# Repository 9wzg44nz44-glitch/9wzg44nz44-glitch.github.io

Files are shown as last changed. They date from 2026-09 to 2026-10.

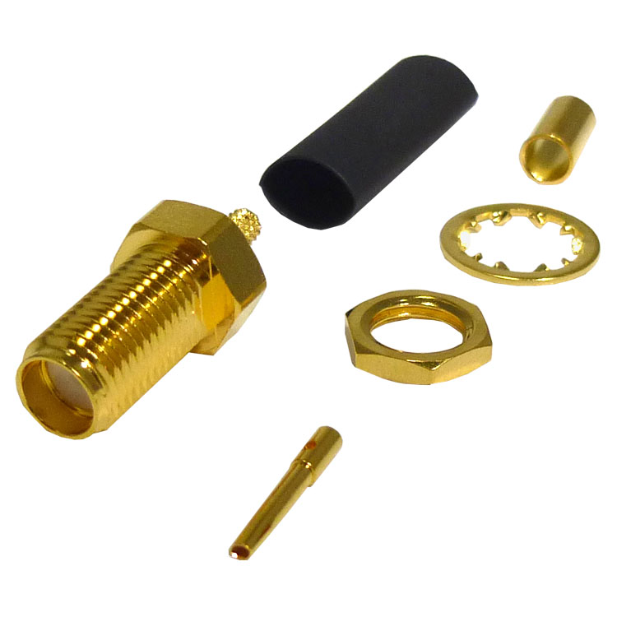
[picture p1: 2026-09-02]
img/901-9875.jpg

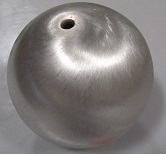
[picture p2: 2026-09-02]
img/kmac-alum-hollow.jpg

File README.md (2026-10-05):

Live site: https://9wzg44nz44-glitch.github.io/

# SLW Hub

Educational static site unifying Dan Britton’s Scalar Longitudinal Wave (SLW) GitHub Pages, plus a **1.3 GHz Faraday-cage lab** (Hively US 9,306,527 scaled off 8 GHz).

**Author:** Dan Britton · BrittonSolutions@icloud.com  
**Source repos:** https://github.com/9wzg44nz44-glitch  
**Prior interactive pages:** built with Grok (xAI), re-homed here as one site.

## How to open

This is vanilla HTML/CSS/JS. No build step.

- Unzip `slw-hub.zip` (or use this folder).
- Open `index.html` in a browser (double-click, or `python3 -m http.server` from this directory and visit `/`).
- Tools, Compare, and the Lab CSV log need JavaScript. The Lab log is stored in `localStorage` until you export CSV.

## Pages

| File | Contents |
|---|---|
| `index.html` | Round 1 landing page: the four benches, tools, and an Archive expander (old `#expt-a` etc. links redirect to `experiments-a-g.html`) |
| `experiments-a-g.html` | The previous home page (JS tabs `#expt-a` `#expt-b` `#kit`), unchanged apart from an archive banner |
| `archive.html` | Every other page, grouped |
| `exp-1296.html`, `exp-433.html`, `exp-2450.html` | Round 1 sphere experiments (1.3 GHz, 433.59 MHz, 2.45 GHz), each with a proposed three-position rod fixture scan (`#stations`). Experiment B (433) runs a full 0 to 360° scan for brass and W1 tool steel (annealed), open bench first, then a planned closed Faraday cage run (`#runs-oct5`, per Dan's Oct 5 email) |
| `oven.html` | Microwave oven experiment (oven as TX, 3/4 in sphere as RX), including the three-position fixture scan adapted for the oven (`#stations`) |
| `todo.html` | Round 1 to-do list (checkboxes saved in localStorage), including the three-position rod fixture scan group (`#g-stations`) |
| `range-finder.html` | Range finding and dipole direction finding, with calculator |
| `joule-loss.html` | Joule loss and power balance, with calculators, including the three-station fixture scan analysis (`#stations`, calculators F and G) |
| `assets/three-station-template.csv` | CSV log template for the three-station scan (station by angle) |
| `learn.html` | Briefing (N–Z vs Hively vs Meyl), detectors, Zimmerman 1296 MHz TM01 hardware, patents |
| `compare.html` | Side-by-side table + illustrative SNR toy |
| `tools.html` | Bifilar pancake + RG-405 length calculator, **default 1.300 GHz**; 1.3 GHz *build* is a sleeve, see `setup.html#sleeve` |
| `setup.html` | Experiment A bench: pancake, mesh tents, **sleeve (not skirt)** how-to `#sleeve` |
| `fields.html` | 1296 MHz TEM vs SLW cartoon |
| `monstein.html` | Experiment B: 433.59 MHz balls + rods, **no balun** |
| `sphere.html` | Fig. 1 vs catalog spheres; **no balun** |
| `kit.html` | Shared submersible field kit (planned; not a claim it has been built) |
| `lab.html` | 1.3 GHz Faraday protocol, HAM legal box, skin-depth table, BOM, controls, CSV log, safety |
| `library.html` | Six bundled PDFs with genre labels |
| `papers/` | Verbatim PDFs (not rewritten) |
| `css/style.css`, `js/*.js`, `assets/mark.svg` | Chrome |
| `assets/site-search.js`, `assets/site-responsive.css`, `search-index.json`, `search.html`, `tools/build_search_index.py` | Site-wide search bar (every page) + responsive layer; rebuild the index with `python3 tools/build_search_index.py` |

## Physics constants used

Skin depth **δ = 1 / √(π f μ σ)** with **σ_Cu ≈ 5.8×10⁷ S/m**, **μ = μ₀**.  
At 1.300 GHz, δ ≈ **1.833 µm**; at 8 GHz, δ ≈ **0.739 µm**.  
At 1296.000 MHz, λ ≈ 231.3 mm; λ/4 sleeve ≈ 57.8 mm in air; first-article stub λ/10 ≈ 23.1 mm. Patent Fig. 2A skirt is historical; the 1.3 GHz build is a close-fitting sleeve.  
Patent Eq. 15: P_rad = I² Z₀ / (4π) with Z₀ ≈ 376.73 Ω.

## Tone

Educational only. SLW is **not** presented as settled physics. No medical, free-energy, or magnetron-oven protocol. 23 cm transmit requires a license; 1296 MHz is a calling frequency.

## Original GitHub Pages fetch (31 Aug 2026)

Fetched successfully (github.io): Educational Briefing; Bifilar Pancake Calculator; Interactive SNR; Combined SNR; Cross-Sectional SNR; Hively SNR Simulator; Mix-and-match antennas; Plasma-tube detector; Why bifilar interacts; No-Skin-effect-3D-plots; RG-405 skirt balun; N–Z 2007 simulation; Meyl–Hively–N–Z; Meyl theory detailed; Linearly Resistive Media; Proposed Experiment — Hively and Microwave Oven.

**404 Pages:** 3D-Field-Patterns-of-SLW-for-Nikolova-Zimmerman-and-Hively; Nikolova-Zimmerman-SLW-florescent-light-bulb---2007-paper; Nikolova-Zimmerman-2007-Light-Bulb; Proposed-Experiment-with-Hively-transmitter-hardware-and-microwave-oven-idea.; Light-bulbs.

No repositories were git-cloned.

© 2026 Dan Britton — research & education.

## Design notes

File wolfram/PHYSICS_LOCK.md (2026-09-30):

# PHYSICS_LOCK: FX1SNR.wl ↔ js/fx1-snr.js (fx1-snr.html)

**Date:** 2026-09-25 (America/New_York)
**PhysicsVersion:** `fx1-snr-v0.2` (v0.1 → v0.2 on 2026-09-25: openEMS FDTD tables became engine physics)
**Single source of truth:** `physics-constants-fx1.json` (repo root; working copy `/workspace/sim-lab/fx1/physics-constants-fx1.json`), section `engine`.
Both twins carry a **generated** copy of `engine`, injected by `gen_constants.mjs` between these markers:
- JS: `/* BEGIN FX1 CONSTANTS … */` … `/* END FX1 CONSTANTS */` (const `K`)
- WL: `(* BEGIN FX1 CONSTANTS … *)` … `(* END FX1 CONSTANTS *)` (`FX1Const`, machine-precision literals `x.xxx`*^n`)

`check_constants.mjs` asserts that both blocks are **bit-identical** to the JSON (2146 comparisons in v0.2, including every embedded openEMS table value; exit 1 on any mismatch).
**CloudPublish:** PENDING SYNC. Target `CloudObject["FX1SNR"]` → https://www.wolframcloud.com/obj/danbritton5/FX1SNR, via `FX1SNR_Publish.wl` (All→Read+Interact). The page shows "Cloud twin pending sync (fx1-snr-v0.2)" (small note at the top and in the Version & sync tab).
**Publishing rule (relaxed 2026-09-25):** the GitHub Pages twin may go live ahead of Cloud. The gap is tracked in `/workspace/sim-lab/SYNC_LEDGER.md`. Re-sync steps: (1) CloudPublish from this exact `FX1SNR.wl`; (2) run `FX1SNR_RunGrid.wl` → `wl_outputs.json`, then `node compare_outputs.mjs js_outputs.json wl_outputs.json` (rel tol 1e-9); (3) remove the "pending sync" note.
**Independent cross-check (done, v0.2):** `py_check.py`, a separate Python implementation from the cited formulas, the JSON and (for the openEMS tables) a direct read of `openems/results.json`, matches `js_outputs.json` on the full v0.2 grid: 2304 records (interior 1260, exterior 768, exterior_sweep 192, interior_interp 84): PASS 104132 / FAIL 0 (rel tol 1e-9, worst 1.35e-14). It also confirms that the 22 engine.openems tables equal the independent results.json read.

**No invented equations.** Every formula below is either a textbook form (FACT, cited), the page's HYP formula copied verbatim, a SleeveBalunSNR (snr-dual-sim-params-v0.2, exterior P_rad updated to the erratum form in fx1-snr-v0.2.1) carry-over, or a labelled ASSUMPTION.

---

## Tags

| Tag | Meaning |
|-----|---|
| **FACT** | Sourced value, or textbook formula form (cited) |
| **DATA / DIGITIZED** | Tekbox chart data points extracted from the PDF vector paths |
| **INTERPOLATED** | Linear in log10(f) between published points. Always labelled in the UI and in the outputs |
| **NOT_PUBLISHED** | No vendor factor at that frequency. Output is null ("floor") and nothing is extrapolated |
| **ASSUMPTION** | Modelling choice (geometry, reference point, rms/peak, leakage combination) |
| **HYP** | EED/SLW hypothesis (future-scalar-ab.html #eed / #home-experiment) or SleeveBalunSNR HYP carry-over |

---

## Constants (engine), with sources

| Key | Value | Tag / source |
|-----|---|---|
| C0, MU0, EPS0, Z0 | 299792458; 4π·1e-7; 8.854187817e-12; 376.73031346177 | FACT, hub physics-constants.json |
| RL | 50 Ω | FACT for the port; applying it to the shell (V0 = √(2·50·P)) is an ASSUMPTION, as on the page |
| Frequencies | 433.59 MHz, 1.296 GHz, 2.45 GHz; free 100–3000 MHz | page / hub |
| Drive | +2 dBm (TinySA + Zeenko ZK06-UM 21 dB, default); −19 dBm (TinySA alone, generator max) | page; tinysa.org TinySA4 spec |
| Radius | bowls 0.14 m (304 SS, seam on); KB-2016 0.03175 m and KB-1820 0.009525 m (3003 Al, no seam) | page; hub setup.html |
| 304 SS | ρ = 72 µΩ·cm → σ = 1.389e6 S/m; μr 1.02 | UPMET 304 datasheet |
| 3003 Al | ρ = 4.16 µΩ·cm → σ = 2.404e7 S/m | MatWeb 3003-H14 |
| Copper / steel / seawater / air | σ 5.8e7 / 5e6 / 4 (εr 80) / ~0 | copied from hub physics-constants.json (SleeveBalunSNR) |
| HDPE | εr 2.29, tanδ 5e-4 | Polymers 2021 13(16):2658, Table 1 |
| Wall thickness | 0.5 mm | ASSUMPTION (slider) |
| Seam gap l, n | 5 mm, 1 | ASSUMPTION; v0.2: used only by seam option `analytic` and the analytic fallback |
| openEMS exterior (engine.openems.exterior) | gap200_433 (page geometry, DEFAULT), gap10_433, gap10_1296, gap10_2450: equatorial |E|, |B| at d = 0.05–1.0 m + NF2FF r = 3, 10 m, per +2 dBm available (50 Ω) | FACT (openEMS FDTD, results.json); ±15% mesh uncertainty |
| openEMS interior (engine.openems.interior.cases) | closed, arc_0p1x30, arc_1x30, ring_0p1, ring_1 (2.5 mm mesh), ring_1_m5 (5 mm mesh); |E|, |B| at r/R 0–0.9 in 3 directions; unresolved flags | FACT, order of magnitude (PEC, stair-stepped, not converged; 10 mm feed-gap runs) |
| Seam default | arc_1x30 (one 30 mm × 1 mm gap) | ASSUMPTION (replaces v0.1's 5 mm analytic seam) |
| Mesh sphere SE | 60 dB below 1 GHz, 50 dB at 1.3 GHz, interpolated between, held above | page catalog; INTERPOLATED / ASSUMPTION |
| Counterpoise gap | 0.20 m (sphere bottom to baking sheet) | page ("at least 20 cm"); reference point is an ASSUMPTION |
| Tents | open 0 / slotted 25 / sealed 55 dB per tent, two tents | SleeveBalunSNR carry-over |
| Sub / seawater lengths, α_toy 0.05 Np/m, cage path 1 m | as in SleeveBalunSNR | carry-over (TOY/HYP) |
| Cavity roots | TM101 2.744, TE101 4.493 | FACT (Harrington 1961 §6-9; Balanis AEE §10.4) |
| Tekbox probe anchors | E5 (dBm @ 1 V/m), H20/H10/H5 (dBm @ 1 µT) | DIGITIZED, TBPS01/TBWA2 manual V2.2, p.2 Picture 2 and p.3 Picture 3 |
| Tekbox FAQ V1.1 | E5 scale 112.5; S: H20 80, H10 62, H5 40 | FACT, FAQ Near Field Probes V1.1 (26-Jan-2022) p.2 |
| TinySA floor | −102 dBm @ 30 kHz RBW (no LNA); −145 dBm @ 200 Hz (LNA, NF 5 dB); P1dB −1; abs max +6; best < −25 dBm | FACT, tinysa.org TinySA4 spec (30 MHz). Applying it at UHF is an ASSUMPTION |

The full values, with the text of every label, are in `physics-constants-fx1.json` → `engine`, `labels`, `formulas`.

---

## Formulas (exact lock; identical code in both twins)

### Drive
```
P = 10^((P_dBm−30)/10);  V0 = sqrt(2·RL·P)  (ASSUMPTION, page);  I_pk = sqrt(2P/RL)  (hub identity)
```
### Exterior, standard — DEFAULT (v0.2): openEMS table (FACT ±15%)
```
dataset = first engine.openems.exterior entry with |f−f_i| ≤ 1e-6 f_i, |R−R_i| ≤ 1e-6 m, counterpoise ON, |gap−gap_i| ≤ 1e-6 m
points = equatorial samples (d_m, E, B) ∪ far-field (ff_r_m − R, ff_E, ff_B), sorted by d
d < d_first → none (analytic);  exact sample → sample;  d > d_last → E_last·(R+d_last)/(R+d) (far field 1/r);  else ln E, ln B linear in ln d
scale s = 10^((P_dBm − 2)/20)  (fields ∝ source EMF; tables per +2 dBm available from 50 Ω)
extModel "auto" = openEMS if available, else B (counterpoise) / A
```
### Interior, standard — DEFAULT (v0.2): openEMS seam tables (FACT, order of magnitude)
```
applies if f = 433.59 MHz, R = 0.14 m (tol as above), solid shell, seam ∈ engine.openems.interior.cases
|E|(r/R), |B|(r/R) along dir ∈ {eq (toward seam), axis, obl}: exact sample (|x−x_i| ≤ 1e-9) → sample; x ≤ x_1 → first; x ≥ x_n → last (clamped);
  else ln|E| linear in r/R when both neighbours > 0, otherwise linear;  unresolved flag = either neighbour flagged
E_leak = s·|E|,  B_leak = s·|B|;  otherwise (or seam "analytic"): v0.1 analytic model below, labelled "analytic only"
```
### Interior, standard — analytic fallback (v0.1 model)
```
Ideal closed conductor: E = 0, B = 0
E_ref = V0/R
SE_wall = A + R + B   (Schelkunoff; Ott 2009 ch.6; exact complex γ, η; plane wave, normal incidence)
SE_seam = max(0, 20log10(λ/2l) − 10log10 n), for l < λ/2   (Ott 2009 §6.6)
SE_shell = −10log10(10^(−SE_wall/10) + 10^(−SE_seam/10))   (ASSUMPTION: incoherent power sum)
E_leak = E_ref·10^(−SE_shell/20), uniform in r (ASSUMPTION);  B_leak = E_leak/C0 (ASSUMPTION)
```
### Interior, HYP (verbatim from the page)
```
E_r = V0 cos(Ωt) R [sin kr − kr cos kr]/(r² sin kR)   (amplitude at cos Ωt = 1; series V0 R k³ r/(3 sin kR) near r = 0)
B = 0; tangential E = 0   (page: "radial (longitudinal), zero at the center, and has B = 0")
```
### Exterior, standard — analytic comparison models (v0.1; fallback when no openEMS data)
```
Q = 4π ε0 R V0                               (FACT; ignores counterpoise proximity = ASSUMPTION)
A: E = V0 R / r_c², B = 0                    (FACT quasi-static; valid for r ≪ λ/2π)
B (fallback default): line current I0 = ωQ from −h_c to +h_c, 400 Hertzian elements   (Balanis 3e Eq. 4-8/4-10; current model = ASSUMPTION)
C: single Hertzian dipole I·l = ω·2h_c·Q at the plane                       (ASSUMPTION)
P_rad (half-space): B by the line-source integral, C = 0.5·Z0·(π/3)(Il/λ)²
Power limit (ON): scale B/C by sqrt(P_drive/P_rad) if P_rad > P_drive   (ASSUMPTION energy bound)
h_c = gap + R;  r_c = R + d
```
### Exterior, HYP (SleeveBalunSNR carry-over)
```
P_OUT(r_c) = S = I_pk² Z0/(2(4π r_c)²)·exp(−αL) W/m² [paper units; total watts P_total (code name P_rad) = 4π r_c² P_OUT = I_pk² Z0/(8π) is DERIVED / ASSUMPTION (spherical integral); patent Eq. 15 total I² Z0/(4π) is twice the erratum-integrated total (documented difference); I = peak confirmed by Dan Britton 2026-09-30; Hively & Loebl 2019 Eq. 38/B5 as corrected by the Erratum, Phys. Essays 32(3) 417 = FACT; I = peak = ASSUMPTION; before 2026-09-29 this was I_pk² Z0/(4π) = patent Eq. 15 = the 2019 form as first printed without the ½];  E∥ = sqrt(S·Z0);  detector power × mP;  B = 0
```
### Stack
```
Standard: Σ SE_layer (same Schelkunoff form) + 2·att_tent   (layers in series, no inter-layer reflections = ASSUMPTION)
HYP: Errata α = 0 (default) → no loss; Ohmic ON → αL = α_toy·ΣL (+ α_toy·2·cage_path) (+ α_extra·L_extra)   (carry-over)
```
### Probe → TinySA
```
P_probe = K(f) + 20log10(field/ref) − stack_dB    (ref = 1 V/m for E5, 1 µT for H probes; field treated as peak = ASSUMPTION)
K(f): manual V2.2 curve (DATA at anchors, INTERPOLATED in log f, NOT_PUBLISHED outside) or FAQ V1.1 formula
floor = LDS + 10log10(RBW/RBW_ref);  SNR = P_probe − floor;  reading = 10log10(10^(P/10) + 10^(floor/10))
```

---

## Lockstep procedure
1. Edit `make_constants.py`, then run `python3 make_constants.py`, `node gen_constants.mjs`, `node check_constants.mjs`.
2. Engine code changes must be made in **both** `js/fx1-snr.js` and `FX1SNR.wl` (same function names: drive/layerSE/seamSE/…/compute ↔ fx1Drive/fx1LayerSE/…/fx1Compute).
3. Run `node dump_js_outputs.mjs` → `js_outputs.json`. In Wolfram, run `wolframscript -file FX1SNR_RunGrid.wl` → `wl_outputs.json`. Then run `node compare_outputs.mjs`.
4. Bump `PHYSICS_VERSION` for any physics change. Publish the Cloud twin (`FX1SNR_Publish.wl`) and update the sync ledger.
5. v0.2: openEMS numbers used by the engine live in `engine.openems`, generated by `make_constants.py` from `openems/results.json`; regenerating them is a physics change (bump the version). `fx1-openems-reference.json` / `FX1OpenEMSReference` / the page's v0.1 reference dump (10 mm geometry) are still regenerated by `merge_openems.mjs` as reference data.
6. Grid v0.2 (`dump_js_outputs.mjs` = `FX1Grid[]` = `py_check.py`): interior radii × drives × factor source × 7 seam options × 3 directions × 5 r/R; exterior radii × drives × factor source × 8 stacks × 8 distances; exterior sweep f ∈ {433.59, 1296, 2450} MHz × gap ∈ {0.01, 0.20} m; interior interpolation r/R ∈ {0.1, 0.6, 0.8, 0.95}.

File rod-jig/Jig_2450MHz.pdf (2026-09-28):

## SLW HUB · ACRYLIC ROD-HOLDING JIG

## DRAFT – for Dan's review

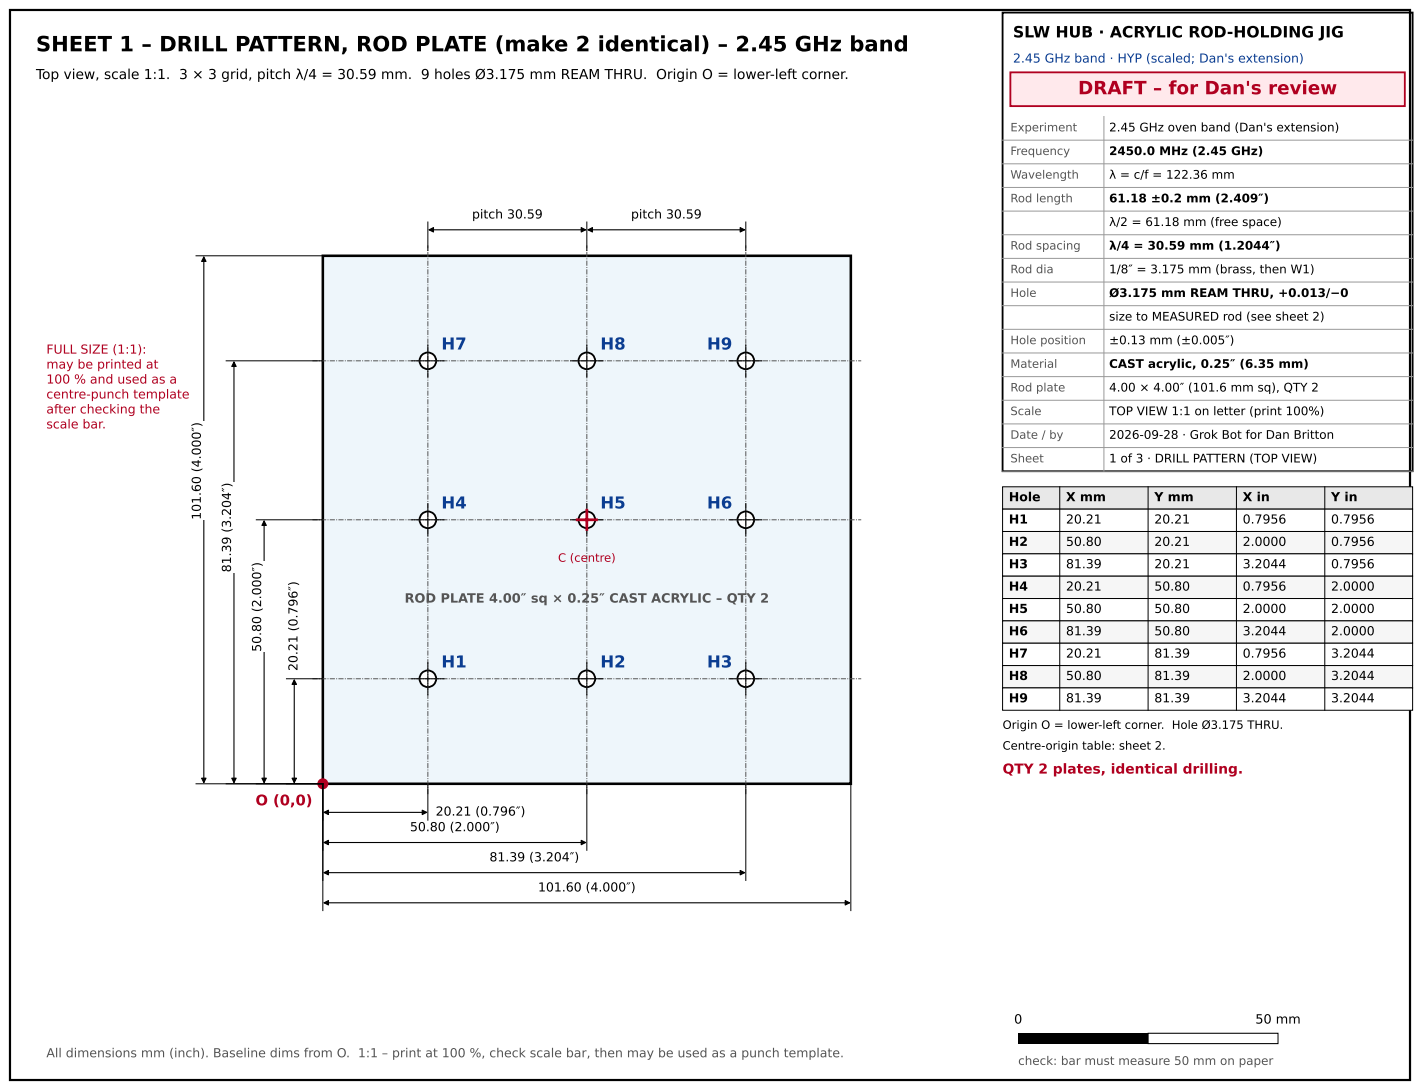
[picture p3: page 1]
Experiment; 2.45 GHz oven band (Dan's extension); Frequency; 2450.0 MHz (2.45 GHz); Wavelength; Rod length; Rod spacing; Rod dia; 1/8″ = 3.175 mm (brass, then W1); Hole; Ø3.175 mm REAM THRU, +0.013/−0; Hole position; Material; CAST acrylic, 0.25″ (6.35 mm); Rod plate; 4.00 × 4.00″ (101.6 mm sq), QTY 2; Scale; TOP VIEW 1:1 on letter (print 100%); Date / by; 2026-09-28 · Grok Bot for Dan Britton; Sheet; 1 of 3 · DRILL PATTERN (TOP VIEW); C (centre); pitch 30.59

SHEET 1 – DRILL PATTERN, ROD PLATE (make 2 identical) – 2.45 GHz band

Top view, scale 1:1. 3 × 3 grid, pitch λ/4 = 30.59 mm. 9 holes Ø3.175 mm REAM THRU. Origin O = lower-left corner.

2.45 GHz band · HYP (scaled; Dan's extension)

λ/2 = 61.18 mm (free space)

size to MEASURED rod (see sheet 2)

FULL SIZE (1:1):
may be printed at
100 % and used as a
centre-punch template
after checking the
scale bar.

ROD PLATE 4.00″ sq × 0.25″ CAST ACRYLIC – QTY 2

Origin O = lower-left corner. Hole Ø3.175 THRU.
Centre-origin table: sheet 2.
QTY 2 plates, identical drilling.

check: bar must measure 50 mm on paper All dimensions mm (inch). Baseline dims from O. 1:1 – print at 100 %, check scale bar, then may be used as a punch template.

## DRAFT – for Dan's review

Experiment | 2.45 GHz oven band (Dan's extension)
Frequency | 2450.0 MHz (2.45 GHz)
Wavelength | λ = c/f = 122.36 mm
Rod length | 61.18 ±0.2 mm (2.409″)
| λ/2 = 61.18 mm (free space)
Rod spacing | λ/4 = 30.59 mm (1.2044″)
Rod dia | 1/8″ = 3.175 mm (brass, then W1)
Hole | Ø3.175 mm REAM THRU, +0.013/−0
| size to MEASURED rod (see sheet 2)
Hole position | ±0.13 mm (±0.005″)
Material | CAST acrylic, 0.25″ (6.35 mm)
Rod plate | 4.00 × 4.00″ (101.6 mm sq), QTY 2
Scale | SECTION 1:1; DETAIL 5:1
Date / by | 2026-09-28 · Grok Bot for Dan Britton
Sheet | 2 of 3 · SECTION A-A, HOLE DETAIL, TABLES

# SHEET 2 – SECTION A-A, HOLE DETAIL, TABLES – 2.45 GHz band

## SECTION A-A through middle column (H2-H5-H8), scale 1:1

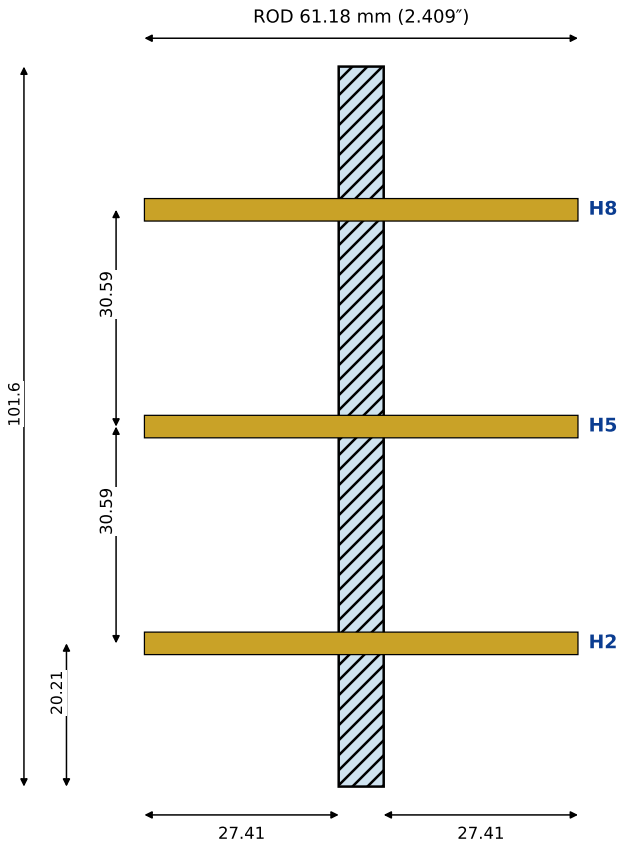
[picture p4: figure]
ROD 61.18 mm (2.409″)

Equal protrusion each side = (L − t)/2 = 27.41 mm (1.079″).

Plate t = 6.35 mm (0.25″). Rods centred at mid-length, like M&W Fig. 2.

Rods: brass first, then W1 – same holes. Rods touch nothing metal (floating). ³⁰.59 30.59 20.21

## DETAIL: ONE HOLE, scale 5:1

Ø3.175 +0.013/−0

REAM THRU

t 6.35

0.4 × 45°
chamfer
BOTH faces

rod
(ghost)

HOLE SPEC (all 9 holes, both plates) – IDEA, see notes

1. Measure 3 rods of EACH material with a micrometer.
2. Pilot drill Ø3.0 mm (or #32 = 0.116″), peck, water mist,

sharp bit with dubbed (0° rake) lips, sacrificial backer.

3. Ream to MEASURED rod dia: nominal 0.1250″ (3.175 mm),

tolerance +0.0005/−0.0000″ (+0.013/−0.000 mm).

= SNUG / TRANSITION fit, NOT a press fit.

4. Chamfer 0.4 × 45° both faces. Try it on the coupon first.
5. Hold rods with silicone O-rings (AS568-005), both faces.

No metal clips or screws on rods: rods stay FLOATING. DO NOT press-fit 0.05–0.10 mm undersize in acrylic:

hoop stress ≈ 5,168–10,337 psi vs 750 psi

continuous limit → cracks / crazing. (#31 was HDPE only.)

Hole | X(O) | Y(O) | X(C) | Y(C) | X(C)in | Y(C)in
H1 | 20.21 | 20.21 | -30.59 | -30.59 | -1.2044 | -1.2044
H2 | 50.80 | 20.21 | +0.00 | -30.59 | +0.0000 | -1.2044
H3 | 81.39 | 20.21 | +30.59 | -30.59 | +1.2044 | -1.2044
H4 | 20.21 | 50.80 | -30.59 | +0.00 | -1.2044 | +0.0000
H5 | 50.80 | 50.80 | +0.00 | +0.00 | +0.0000 | +0.0000
H6 | 81.39 | 50.80 | +30.59 | +0.00 | +1.2044 | +0.0000
H7 | 20.21 | 81.39 | -30.59 | +30.59 | -1.2044 | +1.2044
H8 | 50.80 | 81.39 | +0.00 | +30.59 | +0.0000 | +1.2044
H9 | 81.39 | 81.39 | +30.59 | +30.59 | +1.2044 | +1.2044

mm unless marked. O = lower-left corner;

C = plate centre = H5.
Position tol ±0.13 mm (±0.005″).

## DRAFT – for Dan's review

Experiment | 2.45 GHz oven band (Dan's extension)
Frequency | 2450.0 MHz (2.45 GHz)
Wavelength | λ = c/f = 122.36 mm
Rod length | 61.18 ±0.2 mm (2.409″)
| λ/2 = 61.18 mm (free space)
Rod spacing | λ/4 = 30.59 mm (1.2044″)
Rod dia | 1/8″ = 3.175 mm (brass, then W1)
Hole | Ø3.175 mm REAM THRU, +0.013/−0
| size to MEASURED rod (see sheet 2)
Hole position | ±0.13 mm (±0.005″)
Material | CAST acrylic, 0.25″ (6.35 mm)
Rod plate | 4.00 × 4.00″ (101.6 mm sq), QTY 2
Scale | sketches NOT to scale
Date / by | 2026-09-28 · Grok Bot for Dan Britton
Sheet | 3 of 3 · CUT LIST, ASSEMBLY, NOTES

# SHEET 3 – CUT LIST, ASSEMBLY, NOTES – 2.45 GHz band

Part | Qty | Size (in) | Size (mm) | Operation
Rod plate | 2 | 4 × 4″ | 102 × 102 | drill/ream 9 holes (sheet 1)
H-array base | 1 | 4 × 4″ | 102 × 102 | dado 0.25″ +0.004 wide × 0.125″ deep, centred
V-array legs | 2 | 4 × 2.125″ | 102 × 54 | square ends, no holes
Fit-test coupon | 1 | 3 × 3″ | 76 × 76 | 3 trial holes: reamer sizes

All parts CAST acrylic 0.25″ (6.35 mm), clear. Net area 74.0 in²; +20 % margin 88.8 in²; acrylic mass ≈ 0.36 kg.

BUY: 1 sheet 12 × 12″ × 0.25″ cast acrylic (fits by guillotine nesting, 1/8″ kerf) – or order the parts cut to size.

V-array leg height 2.125″ = rod protrusion 27.4 mm + 25 mm clearance to the stand (IDEA).

Join: Weld-On 16 (or 4) solvent cement; anneal machined parts before cementing (acrylic makers' advice). NO metal fasteners near the rods.

turntable

rotate about
vertical axis
→ angle φ

H ARRAY (rods horizontal, rotatable)

rod plate stands in a half-depth dado in the base, cemented

V ARRAY (rods vertical, fixed)

rod plate horizontal, cemented between 2 legs

Keep steel (turntable bearing, screws) ≥ λ/(2π) = 20 mm from the nearest rod: add a wood/plastic riser under the base if needed (IDEA).

Stand height: centre rod H5 on the TX–RX ball axis. Height is an OPEN item (depends on ball mounts).

FACT | Monstein & Wesley, EPL 59(4) 514 (2002) p.516: 'cubic array of 9 wires of length λ/2 (34.6 cm)' as polarizer-analyzer at 433.59 MHz;
| brass rods; Fig. 2 photo: rods pass through ONE board at mid-length; 'Two such arrays with wires perpendicular to the
| direction of propagation and to each other'. Rod spacing, rod diameter and board size are NOT stated. Ball antennas 6 cm dia.
FACT | Butterworth et al., J. Sci. Explor. 27(1) 13-23 (2013) p.16 (446 MHz rebuild): '3 × 3 arrays, a half-wavelength long and a
| quarter-wave apart, one horizontal and one vertical. The horizontal polarizer can be rotated.' → λ/4 pitch comes from Butterworth.
HYP | Frequency/scaling: M&W's λ/2 rods and Butterworth's λ/4 pitch scaled to this frequency (Dan's extension; not in either paper).
HYP | 'Cubic' read as: 3 × 3 at λ/4 spans λ/2, equal to the rod length, so the array fills a λ/2 cube.
IDEA | Acrylic replaces the earlier HDPE fixtures (rod-fixtures rev A) as requested. Single plate at rod mid-length follows M&W Fig. 2.
IDEA | Plate t/L = 0.104: plastic covers a small part of each rod. Rods electrically FLOATING, no wires, as in M&W.
IDEA | 1/8″ rods: stock on hand/ordered (brass + W1), same holes for both; half-rod self-weight sag < 0.01 mm (brass).
NOTE | Rod material enters M&W's model only through σ (eq. 7); geometry is identical for brass and W1 rods.

ASSEMBLY ORDER

1. Cut & drill coupon; pick reamer that gives a snug push fit by hand.
2. Drill/ream both rod plates together

(stacked, pinned) so patterns match.

3. Anneal, then cement H plate into base

dado; cement V plate between legs.

4. Push rods in, centre them (equal

27.4 mm each side), add O-rings.
5. Brass first; later swap to W1 rods

(same holes, same geometry).

Files: numbers.json, src/*.py

/workspace/sim-lab/rod-jig/

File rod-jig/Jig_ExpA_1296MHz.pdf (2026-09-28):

## SLW HUB · ACRYLIC ROD-HOLDING JIG

## DRAFT – for Dan's review

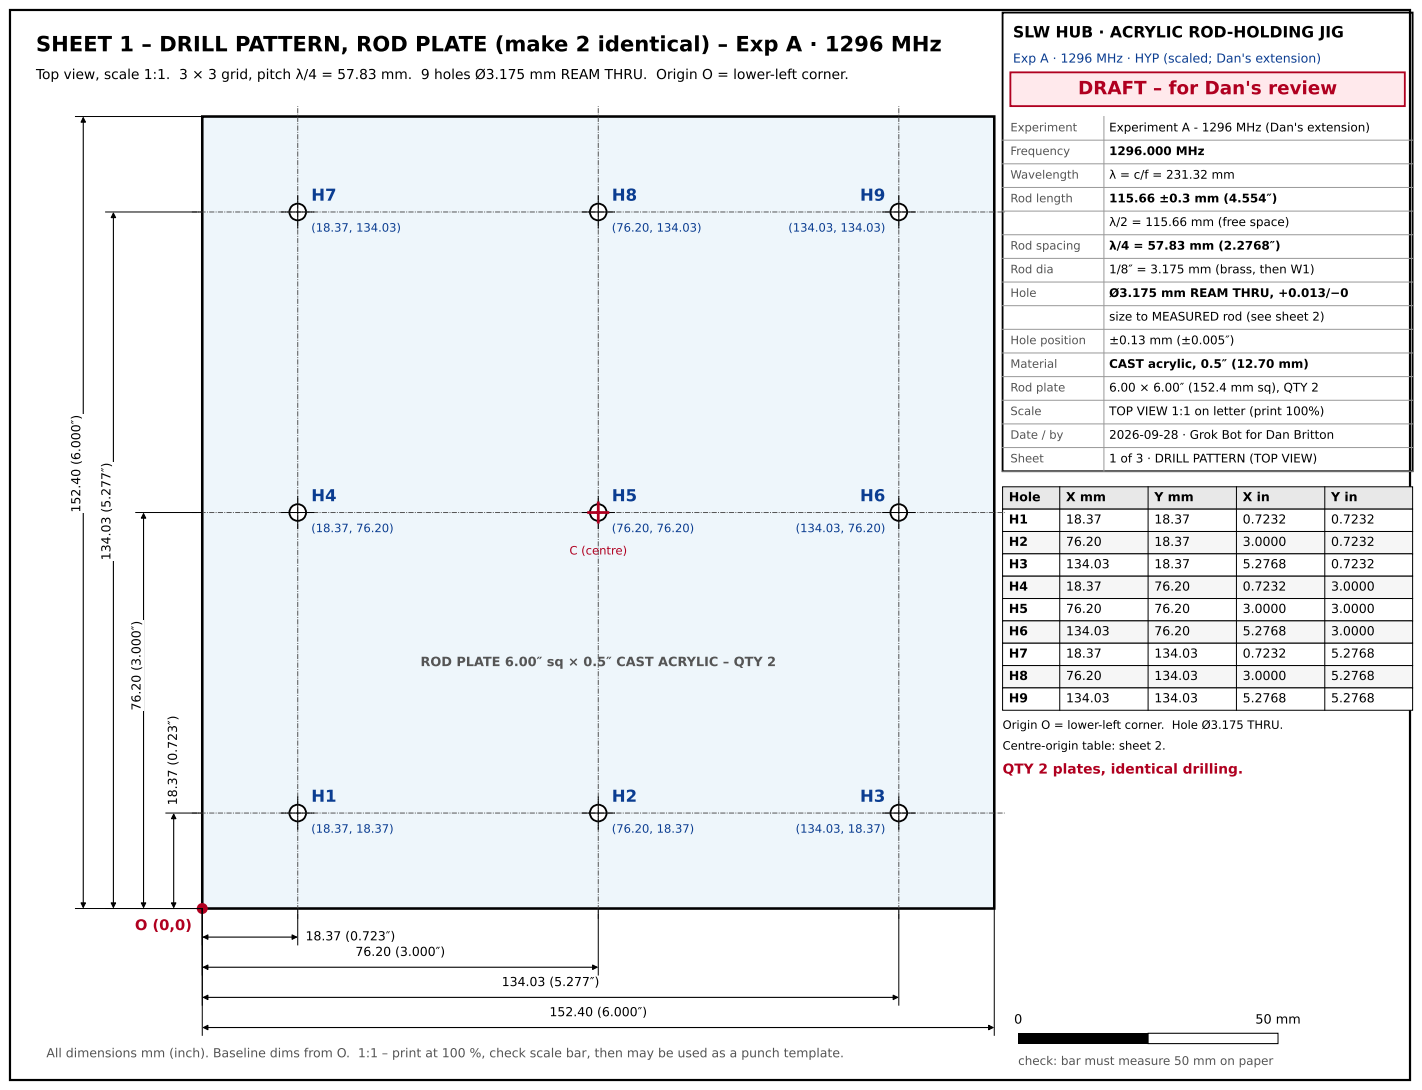
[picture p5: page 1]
Experiment; Experiment A - 1296 MHz (Dan's extension); Frequency; 1296.000 MHz; Wavelength; Rod length; Rod spacing; Rod dia; 1/8″ = 3.175 mm (brass, then W1); Hole; Ø3.175 mm REAM THRU, +0.013/−0; Hole position; Material; CAST acrylic, 0.5″ (12.70 mm); Rod plate; 6.00 × 6.00″ (152.4 mm sq), QTY 2; Scale; TOP VIEW 1:1 on letter (print 100%); Date / by; 2026-09-28 · Grok Bot for Dan Britton; Sheet; 1 of 3 · DRILL PATTERN (TOP VIEW); C (centre)

SHEET 1 – DRILL PATTERN, ROD PLATE (make 2 identical) – Exp A · 1296 MHz

Top view, scale 1:1. 3 × 3 grid, pitch λ/4 = 57.83 mm. 9 holes Ø3.175 mm REAM THRU. Origin O = lower-left corner.

Exp A · 1296 MHz · HYP (scaled; Dan's extension)

λ/2 = 115.66 mm (free space)

size to MEASURED rod (see sheet 2)

ROD PLATE 6.00″ sq × 0.5″ CAST ACRYLIC – QTY 2

Origin O = lower-left corner. Hole Ø3.175 THRU.
Centre-origin table: sheet 2.
QTY 2 plates, identical drilling.

check: bar must measure 50 mm on paper All dimensions mm (inch). Baseline dims from O. 1:1 – print at 100 %, check scale bar, then may be used as a punch template.

## DRAFT – for Dan's review

Experiment | Experiment A - 1296 MHz (Dan's extension)
Frequency | 1296.000 MHz
Wavelength | λ = c/f = 231.32 mm
Rod length | 115.66 ±0.3 mm (4.554″)
| λ/2 = 115.66 mm (free space)
Rod spacing | λ/4 = 57.83 mm (2.2768″)
Rod dia | 1/8″ = 3.175 mm (brass, then W1)
Hole | Ø3.175 mm REAM THRU, +0.013/−0
| size to MEASURED rod (see sheet 2)
Hole position | ±0.13 mm (±0.005″)
Material | CAST acrylic, 0.5″ (12.70 mm)
Rod plate | 6.00 × 6.00″ (152.4 mm sq), QTY 2
Scale | SECTION 1:2; DETAIL 5:1
Date / by | 2026-09-28 · Grok Bot for Dan Britton
Sheet | 2 of 3 · SECTION A-A, HOLE DETAIL, TABLES

# SHEET 2 – SECTION A-A, HOLE DETAIL, TABLES – Exp A · 1296 MHz

## SECTION A-A through middle column (H2-H5-H8), scale 1:2

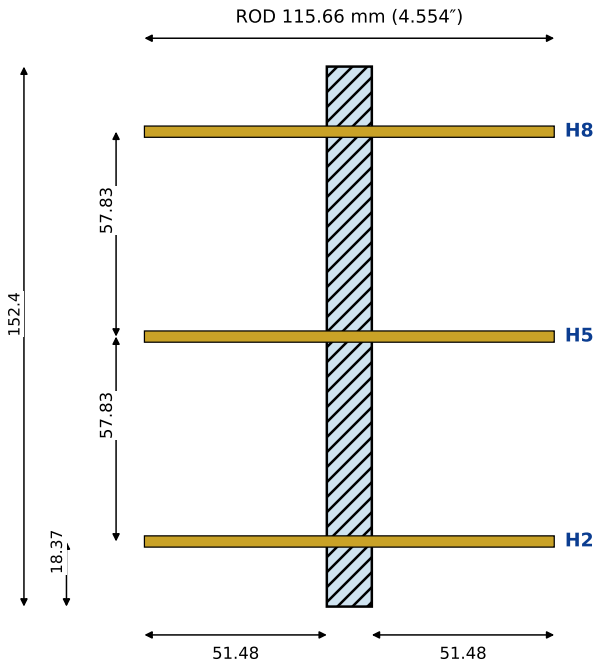
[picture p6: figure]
ROD 115.66 mm (4.554″)

Equal protrusion each side = (L − t)/2 = 51.48 mm (2.027″).

Plate t = 12.70 mm (0.5″). Rods centred at mid-length, like M&W Fig. 2.

Rods: brass first, then W1 – same holes. Rods touch nothing metal (floating). ⁵⁷.83 57.83 18.37

## DETAIL: ONE HOLE, scale 5:1

Ø3.175 +0.013/−0

REAM THRU

t 12.70

0.4 × 45°
chamfer
BOTH faces

rod
(ghost)

HOLE SPEC (all 9 holes, both plates) – IDEA, see notes

1. Measure 3 rods of EACH material with a micrometer.
2. Pilot drill Ø3.0 mm (or #32 = 0.116″), peck, water mist,

sharp bit with dubbed (0° rake) lips, sacrificial backer.

3. Ream to MEASURED rod dia: nominal 0.1250″ (3.175 mm),

tolerance +0.0005/−0.0000″ (+0.013/−0.000 mm).

= SNUG / TRANSITION fit, NOT a press fit.

4. Chamfer 0.4 × 45° both faces. Try it on the coupon first.
5. Hold rods with silicone O-rings (AS568-005), both faces.

No metal clips or screws on rods: rods stay FLOATING. DO NOT press-fit 0.05–0.10 mm undersize in acrylic:

hoop stress ≈ 5,168–10,337 psi vs 750 psi

continuous limit → cracks / crazing. (#31 was HDPE only.)

Hole | X(O) | Y(O) | X(C) | Y(C) | X(C)in | Y(C)in
H1 | 18.37 | 18.37 | -57.83 | -57.83 | -2.2768 | -2.2768
H2 | 76.20 | 18.37 | +0.00 | -57.83 | +0.0000 | -2.2768
H3 | 134.03 | 18.37 | +57.83 | -57.83 | +2.2768 | -2.2768
H4 | 18.37 | 76.20 | -57.83 | +0.00 | -2.2768 | +0.0000
H5 | 76.20 | 76.20 | +0.00 | +0.00 | +0.0000 | +0.0000
H6 | 134.03 | 76.20 | +57.83 | +0.00 | +2.2768 | +0.0000
H7 | 18.37 | 134.03 | -57.83 | +57.83 | -2.2768 | +2.2768
H8 | 76.20 | 134.03 | +0.00 | +57.83 | +0.0000 | +2.2768
H9 | 134.03 | 134.03 | +57.83 | +57.83 | +2.2768 | +2.2768

mm unless marked. O = lower-left corner;

C = plate centre = H5.
Position tol ±0.13 mm (±0.005″).

## DRAFT – for Dan's review

Experiment | Experiment A - 1296 MHz (Dan's extension)
Frequency | 1296.000 MHz
Wavelength | λ = c/f = 231.32 mm
Rod length | 115.66 ±0.3 mm (4.554″)
| λ/2 = 115.66 mm (free space)
Rod spacing | λ/4 = 57.83 mm (2.2768″)
Rod dia | 1/8″ = 3.175 mm (brass, then W1)
Hole | Ø3.175 mm REAM THRU, +0.013/−0
| size to MEASURED rod (see sheet 2)
Hole position | ±0.13 mm (±0.005″)
Material | CAST acrylic, 0.5″ (12.70 mm)
Rod plate | 6.00 × 6.00″ (152.4 mm sq), QTY 2
Scale | sketches NOT to scale
Date / by | 2026-09-28 · Grok Bot for Dan Britton
Sheet | 3 of 3 · CUT LIST, ASSEMBLY, NOTES

# SHEET 3 – CUT LIST, ASSEMBLY, NOTES – Exp A · 1296 MHz

Part | Qty | Size (in) | Size (mm) | Operation
Rod plate | 2 | 6 × 6″ | 152 × 152 | drill/ream 9 holes (sheet 1)
H-array base | 1 | 6 × 6″ | 152 × 152 | dado 0.5″ +0.004 wide × 0.25″ deep, centred
V-array legs | 2 | 6 × 3.125″ | 152 × 79 | square ends, no holes
Fit-test coupon | 1 | 3 × 3″ | 76 × 76 | 3 trial holes: reamer sizes

All parts CAST acrylic 0.5″ (12.70 mm), clear. Net area 154.5 in²; +20 % margin 185.4 in²; acrylic mass ≈ 1.51 kg.

BUY: 1 sheet 12 × 24″ × 0.5″ cast acrylic (fits by guillotine nesting, 1/8″ kerf) – or order the parts cut to size.

V-array leg height 3.125″ = rod protrusion 51.5 mm + 25 mm clearance to the stand (IDEA).

Join: Weld-On 16 (or 4) solvent cement; anneal machined parts before cementing (acrylic makers' advice). NO metal fasteners near the rods.

turntable

rotate about
vertical axis
→ angle φ

H ARRAY (rods horizontal, rotatable)

rod plate stands in a half-depth dado in the base, cemented

V ARRAY (rods vertical, fixed)

rod plate horizontal, cemented between 2 legs

Keep steel (turntable bearing, screws) ≥ λ/(2π) = 37 mm from the nearest rod: add a wood/plastic riser under the base if needed (IDEA).

Stand height: centre rod H5 on the TX–RX ball axis. Height is an OPEN item (depends on ball mounts).

FACT | Monstein & Wesley, EPL 59(4) 514 (2002) p.516: 'cubic array of 9 wires of length λ/2 (34.6 cm)' as polarizer-analyzer at 433.59 MHz;
| brass rods; Fig. 2 photo: rods pass through ONE board at mid-length; 'Two such arrays with wires perpendicular to the
| direction of propagation and to each other'. Rod spacing, rod diameter and board size are NOT stated. Ball antennas 6 cm dia.
FACT | Butterworth et al., J. Sci. Explor. 27(1) 13-23 (2013) p.16 (446 MHz rebuild): '3 × 3 arrays, a half-wavelength long and a
| quarter-wave apart, one horizontal and one vertical. The horizontal polarizer can be rotated.' → λ/4 pitch comes from Butterworth.
HYP | Frequency/scaling: M&W's λ/2 rods and Butterworth's λ/4 pitch scaled to this frequency (Dan's extension; not in either paper).
HYP | 'Cubic' read as: 3 × 3 at λ/4 spans λ/2, equal to the rod length, so the array fills a λ/2 cube.
IDEA | Acrylic replaces the earlier HDPE fixtures (rod-fixtures rev A) as requested. Single plate at rod mid-length follows M&W Fig. 2.
IDEA | Plate t/L = 0.110: plastic covers a small part of each rod. Rods electrically FLOATING, no wires, as in M&W.
IDEA | 1/8″ rods: stock on hand/ordered (brass + W1), same holes for both; half-rod self-weight sag < 0.01 mm (brass).
NOTE | Rod material enters M&W's model only through σ (eq. 7); geometry is identical for brass and W1 rods.

ASSEMBLY ORDER

1. Cut & drill coupon; pick reamer that gives a snug push fit by hand.
2. Drill/ream both rod plates together

(stacked, pinned) so patterns match.

3. Anneal, then cement H plate into base

dado; cement V plate between legs.

4. Push rods in, centre them (equal

51.5 mm each side), add O-rings.
5. Brass first; later swap to W1 rods

(same holes, same geometry).

Files: numbers.json, src/*.py

/workspace/sim-lab/rod-jig/

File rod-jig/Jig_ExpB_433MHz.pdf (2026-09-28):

## SLW HUB · ACRYLIC ROD-HOLDING JIG

## DRAFT – for Dan's review

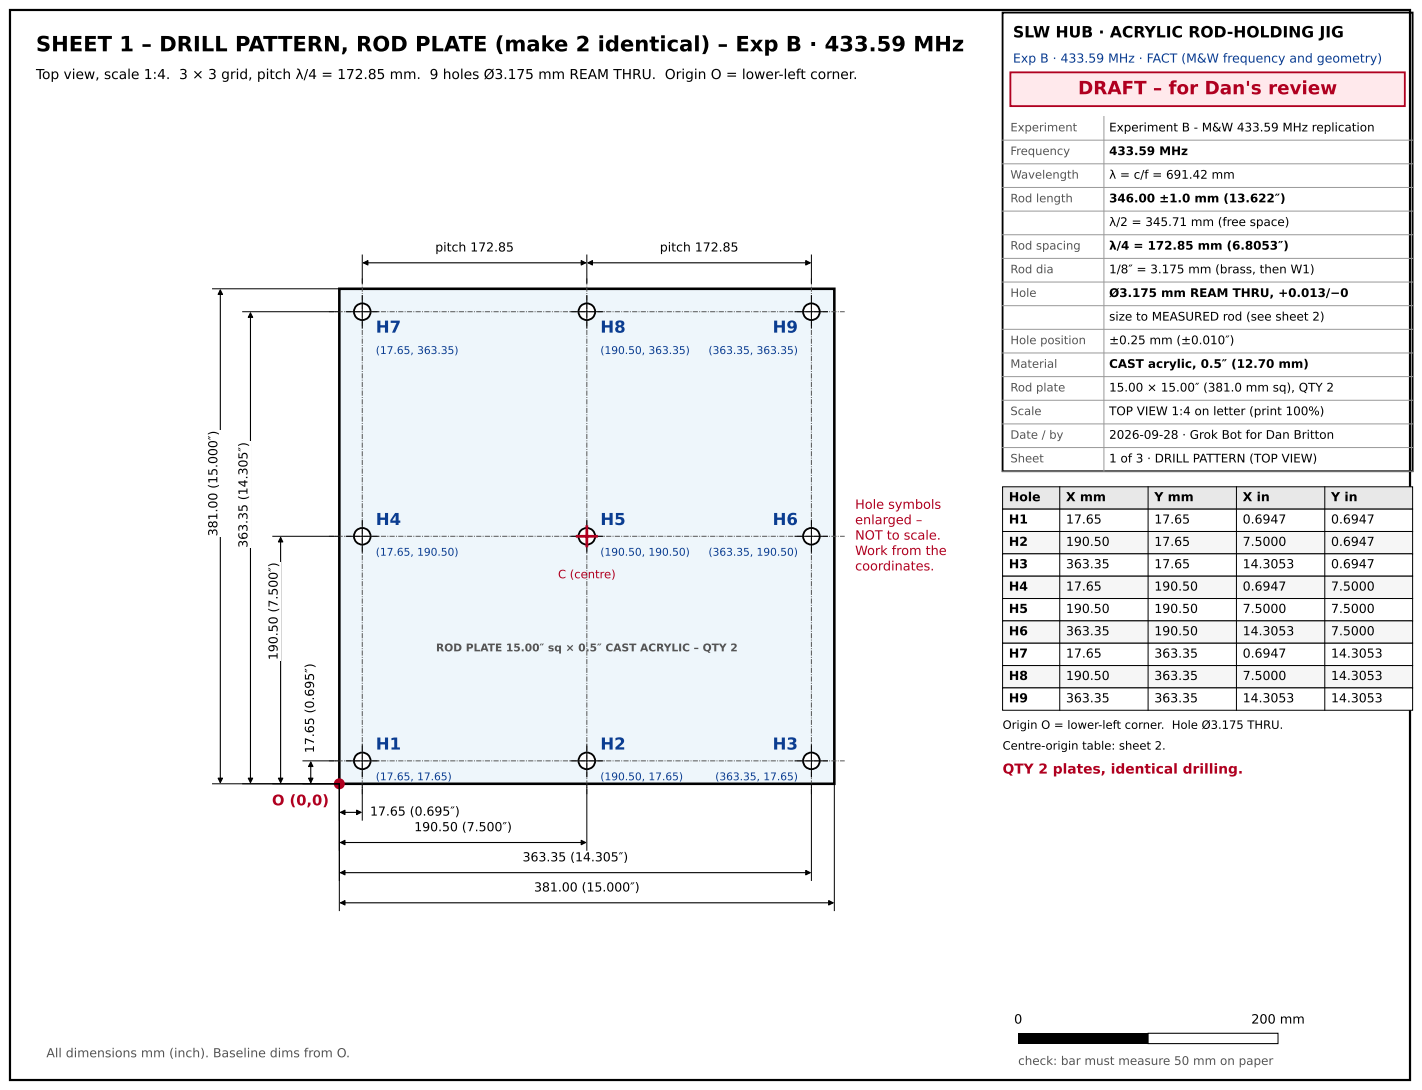
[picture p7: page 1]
Experiment; Experiment B - M&W 433.59 MHz replication; Frequency; 433.59 MHz; Wavelength; Rod length; Rod spacing; Rod dia; 1/8″ = 3.175 mm (brass, then W1); Hole; Ø3.175 mm REAM THRU, +0.013/−0; Hole position; Material; CAST acrylic, 0.5″ (12.70 mm); Rod plate; 15.00 × 15.00″ (381.0 mm sq), QTY 2; Scale; TOP VIEW 1:4 on letter (print 100%); Date / by; 2026-09-28 · Grok Bot for Dan Britton; Sheet; 1 of 3 · DRILL PATTERN (TOP VIEW); C (centre); pitch 172.85

SHEET 1 – DRILL PATTERN, ROD PLATE (make 2 identical) – Exp B · 433.59 MHz

Top view, scale 1:4. 3 × 3 grid, pitch λ/4 = 172.85 mm. 9 holes Ø3.175 mm REAM THRU. Origin O = lower-left corner.

Exp B · 433.59 MHz · FACT (M&W frequency and geometry)

λ/2 = 345.71 mm (free space)

size to MEASURED rod (see sheet 2)

Hole symbols
enlarged –
NOT to scale.
Work from the
coordinates.

ROD PLATE 15.00″ sq × 0.5″ CAST ACRYLIC – QTY 2

Origin O = lower-left corner. Hole Ø3.175 THRU.
Centre-origin table: sheet 2.
QTY 2 plates, identical drilling.

check: bar must measure 50 mm on paper All dimensions mm (inch). Baseline dims from O.

## DRAFT – for Dan's review

Experiment | Experiment B - M&W 433.59 MHz replication
Frequency | 433.59 MHz
Wavelength | λ = c/f = 691.42 mm
Rod length | 346.00 ±1.0 mm (13.622″)
| λ/2 = 345.71 mm (free space)
Rod spacing | λ/4 = 172.85 mm (6.8053″)
Rod dia | 1/8″ = 3.175 mm (brass, then W1)
Hole | Ø3.175 mm REAM THRU, +0.013/−0
| size to MEASURED rod (see sheet 2)
Hole position | ±0.25 mm (±0.010″)
Material | CAST acrylic, 0.5″ (12.70 mm)
Rod plate | 15.00 × 15.00″ (381.0 mm sq), QTY 2
Scale | SECTION 1:4; DETAIL 5:1
Date / by | 2026-09-28 · Grok Bot for Dan Britton
Sheet | 2 of 3 · SECTION A-A, HOLE DETAIL, TABLES

# SHEET 2 – SECTION A-A, HOLE DETAIL, TABLES – Exp B · 433.59 MHz

## SECTION A-A through middle column (H2-H5-H8), scale 1:4

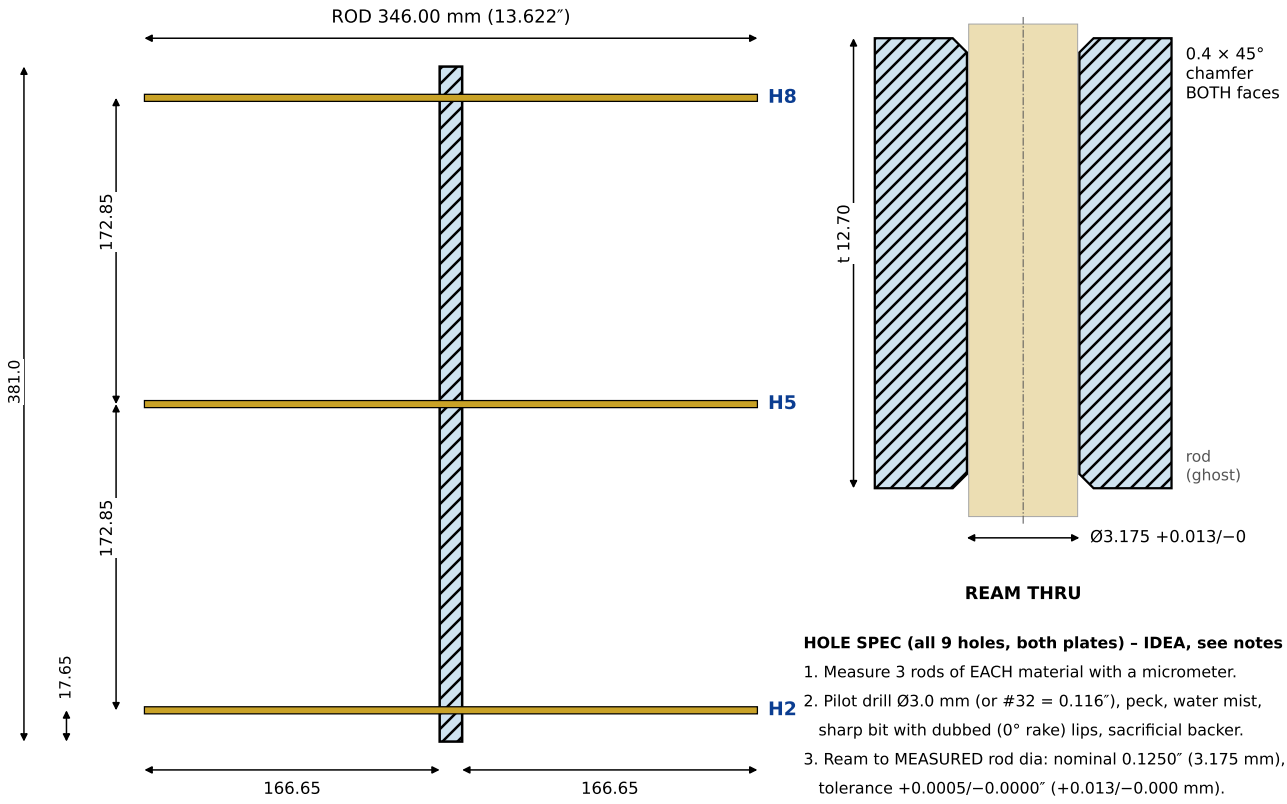
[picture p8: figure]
ROD 346.00 mm (13.622″); REAM THRU; 0.4 × 45° chamfer BOTH faces; rod (ghost); tolerance +0.0005/−0.0000″ (+0.013/−0.000 mm).

Equal protrusion each side = (L − t)/2 = 166.65 mm (6.561″).

Plate t = 12.70 mm (0.5″). Rods centred at mid-length, like M&W Fig. 2.

Rods: brass first, then W1 – same holes. Rods touch nothing metal (floating). ¹⁷².85 172.85 17.65

## DETAIL: ONE HOLE, scale 5:1

HOLE SPEC (all 9 holes, both plates) – IDEA, see notes

1. Measure 3 rods of EACH material with a micrometer.
2. Pilot drill Ø3.0 mm (or #32 = 0.116″), peck, water mist,

sharp bit with dubbed (0° rake) lips, sacrificial backer.

3. Ream to MEASURED rod dia: nominal 0.1250″ (3.175 mm),

= SNUG / TRANSITION fit, NOT a press fit.

4. Chamfer 0.4 × 45° both faces. Try it on the coupon first.
5. Hold rods with silicone O-rings (AS568-005), both faces.

No metal clips or screws on rods: rods stay FLOATING. DO NOT press-fit 0.05–0.10 mm undersize in acrylic:

hoop stress ≈ 5,168–10,337 psi vs 750 psi

continuous limit → cracks / crazing. (#31 was HDPE only.)

Hole | X(O) | Y(O) | X(C) | Y(C) | X(C)in | Y(C)in
H1 | 17.65 | 17.65 | -172.85 | -172.85 | -6.8053 | -6.8053
H2 | 190.50 | 17.65 | +0.00 | -172.85 | +0.0000 | -6.8053
H3 | 363.35 | 17.65 | +172.85 | -172.85 | +6.8053 | -6.8053
H4 | 17.65 | 190.50 | -172.85 | +0.00 | -6.8053 | +0.0000
H5 | 190.50 | 190.50 | +0.00 | +0.00 | +0.0000 | +0.0000
H6 | 363.35 | 190.50 | +172.85 | +0.00 | +6.8053 | +0.0000
H7 | 17.65 | 363.35 | -172.85 | +172.85 | -6.8053 | +6.8053
H8 | 190.50 | 363.35 | +0.00 | +172.85 | +0.0000 | +6.8053
H9 | 363.35 | 363.35 | +172.85 | +172.85 | +6.8053 | +6.8053

mm unless marked. O = lower-left corner;

C = plate centre = H5.
Position tol ±0.25 mm (±0.010″).

## DRAFT – for Dan's review

Experiment | Experiment B - M&W 433.59 MHz replication
Frequency | 433.59 MHz
Wavelength | λ = c/f = 691.42 mm
Rod length | 346.00 ±1.0 mm (13.622″)
| λ/2 = 345.71 mm (free space)
Rod spacing | λ/4 = 172.85 mm (6.8053″)
Rod dia | 1/8″ = 3.175 mm (brass, then W1)
Hole | Ø3.175 mm REAM THRU, +0.013/−0
| size to MEASURED rod (see sheet 2)
Hole position | ±0.25 mm (±0.010″)
Material | CAST acrylic, 0.5″ (12.70 mm)
Rod plate | 15.00 × 15.00″ (381.0 mm sq), QTY 2
Scale | sketches NOT to scale
Date / by | 2026-09-28 · Grok Bot for Dan Britton
Sheet | 3 of 3 · CUT LIST, ASSEMBLY, NOTES

# SHEET 3 – CUT LIST, ASSEMBLY, NOTES – Exp B · 433.59 MHz

Part | Qty | Size (in) | Size (mm) | Operation
Rod plate | 2 | 15 × 15″ | 381 × 381 | drill/ream 9 holes (sheet 1)
H-array base | 1 | 15 × 15″ | 381 × 381 | dado 0.5″ +0.004 wide × 0.25″ deep, centred
V-array legs | 2 | 15 × 7.625″ | 381 × 194 | square ends, no holes
Fit-test coupon | 1 | 3 × 3″ | 76 × 76 | 3 trial holes: reamer sizes

All parts CAST acrylic 0.5″ (12.70 mm), clear. Net area 912.8 in²; +20 % margin 1095.3 in²; acrylic mass ≈ 8.90 kg.

BUY: 1 sheet 24 × 48″ × 0.5″ cast acrylic (fits by guillotine nesting, 1/8″ kerf) – or order the parts cut to size.

V-array leg height 7.625″ = rod protrusion 166.7 mm + 25 mm clearance to the stand (IDEA).

Join: Weld-On 16 (or 4) solvent cement; anneal machined parts before cementing (acrylic makers' advice). NO metal fasteners near the rods.

turntable

rotate about
vertical axis
→ angle φ

H ARRAY (rods horizontal, rotatable)

rod plate stands in a half-depth dado in the base, cemented

V ARRAY (rods vertical, fixed)

rod plate horizontal, cemented between 2 legs

Keep steel (turntable bearing, screws) ≥ λ/(2π) = 110 mm from the nearest rod: add a wood/plastic riser under the base if needed (IDEA).

Stand height: centre rod H5 on the TX–RX ball axis. Height is an OPEN item (depends on ball mounts).

FACT | Monstein & Wesley, EPL 59(4) 514 (2002) p.516: 'cubic array of 9 wires of length λ/2 (34.6 cm)' as polarizer-analyzer at 433.59 MHz;
| brass rods; Fig. 2 photo: rods pass through ONE board at mid-length; 'Two such arrays with wires perpendicular to the
| direction of propagation and to each other'. Rod spacing, rod diameter and board size are NOT stated. Ball antennas 6 cm dia.
FACT | Butterworth et al., J. Sci. Explor. 27(1) 13-23 (2013) p.16 (446 MHz rebuild): '3 × 3 arrays, a half-wavelength long and a
| quarter-wave apart, one horizontal and one vertical. The horizontal polarizer can be rotated.' → λ/4 pitch comes from Butterworth.
FACT | Frequency/scaling: 433.59 MHz and 34.6 cm are M&W's own numbers.
HYP | 'Cubic' read as: 3 × 3 at λ/4 spans λ/2, equal to the rod length, so the array fills a λ/2 cube.
IDEA | Acrylic replaces the earlier HDPE fixtures (rod-fixtures rev A) as requested. Single plate at rod mid-length follows M&W Fig. 2.
IDEA | Plate t/L = 0.037: plastic covers a small part of each rod. Rods electrically FLOATING, no wires, as in M&W.
IDEA | 1/8″ rods: stock on hand/ordered (brass + W1), same holes for both; half-rod self-weight sag 0.13 mm (brass).
NOTE | Rod material enters M&W's model only through σ (eq. 7); geometry is identical for brass and W1 rods.

ASSEMBLY ORDER

1. Cut & drill coupon; pick reamer that gives a snug push fit by hand.
2. Drill/ream both rod plates together

(stacked, pinned) so patterns match.

3. Anneal, then cement H plate into base

dado; cement V plate between legs.

4. Push rods in, centre them (equal

166.7 mm each side), add O-rings.
5. Brass first; later swap to W1 rods

(same holes, same geometry).

Files: numbers.json, src/*.py

/workspace/sim-lab/rod-jig/

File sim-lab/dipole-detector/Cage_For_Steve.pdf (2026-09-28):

# A SHIELDED BOX FOR THE DIPOLE DETECTOR

Plain-English build guide for Steve · full details and sources in CAGE_ESTIMATE.md
THE ONE RULE: NOTHING GOES THROUGH THE WALL.

No cables, no connectors, no feed-throughs. The TinySA runs on its own battery inside; save the reading and read it after opening the lid. The box keeps ordinary radio out; the dipole is its own instrument with its own box (not shared with the coil cage, the Experiment B rods, or the oven).

## 1. WHICH SIZE (inside dimensions)

Box | Use for | Gap to walls | OK?
60 × 60 × 60 cm (24 × 24 × 24 in) | DD-1296, DD-2450 | ≥ 1.06 wavelength | YES — Option 1
100 × 60 × 60 cm (39 × 24 × 24 in) | DD-433 (and the other two) | ≈ 0.43–0.49 wavelength | YES — Option 2
30 cm cube, or 40 × 20 × 15 cm | — | far too close | NO
120 × 60 × 60 cm | — | box itself rings at 433 MHz | AVOID

Why: metal walls closer than about half a wavelength to one wavelength change how the dipole tunes (rule of thumb). Even in the right box, re-check the dipole's tuning INSIDE the closed box and write it down.

## 2. WHAT IT LOOKS LIKE

LID with a 5 cm (2 in) lip that folds down over the walls

IR tube (copper pipe, see 5)

TinySA on battery, in a corner

dipole in the
middle, on its plate

Copper mesh on a wood or
plastic frame. Seams
overlapped and soldered.

## 3. MATERIAL (pick one)

- BEST: 16-mesh copper screen (TWP). You can solder the seams.
- FASTEST: nickel-copper shielding fabric (Less EMF), sewn or taped into a bag with a roll-down top.
- CHEAPEST: aluminium window screen ($41.55 a roll). Can't be soldered, so seams are weaker.
- How much: Option 1 about 3.2 m² (34 ft²), Option 2 about 4.5 m² (48 ft²), incl. overlaps + 20 % spare.

## 4. BUILD TIPS

- Overlap every seam 2–5 cm and solder it (copper), or cover both sides with copper tape that has CONDUCTIVE glue.
- The lid must touch all the way round — not just at a few clamps. Use metal finger strip or a conductive
gasket, or press the lip flat with a wooden strip clamped at each end. Any hole or gap: keep it under 6 mm.
- No ground wire needed: a closed box with no holes shields without one. A ground on the OUTSIDE is optional.

## 5. IR THERMOMETER HOLE

3/4 in Type L copper pipe (inside 20 mm), 80 mm (3.15 in) long, soldered all round into a copper plate in the wall. It blocks ordinary radio (about 128 dB by the standard formula) but light and infrared go straight through.
Put the IR gun right against the pipe. Keep a copper end cap: readings open vs capped are also a test.

COST + TIME (estimate)

Option 1: about $155–310, 9–12 hours
Option 2: about $190–420, 12–16 hours (fabric bag: 3–6 h)

Dipole Detector cage · Rev A 2026-09-27 Grok Bot initial estimate — VERIFY

Prepared for Dan Britton (builder: Steve)

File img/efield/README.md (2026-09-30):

# E∥ field-map PNG assets (CoS Mathematica)

**Physics:** `snr-dual-sim-params-v0.1.1` / `efield-maps-v0`  
**Cloud:** https://www.wolframcloud.com/obj/danbritton5/SleeveBalunEFieldMaps  
**Lock:** `efield_summary.json` — E(10 m)=1.504e-3 V/m; E(λ)=2.176e-2 / 6.503e-2 / 1.229e-1 (433.59 / 1296 / 2450) at TinySA −19 dBm, with P_OUT(r) = I_pk² Z0/[2(4π r)²] W/m² (Hively & Loebl 2019 Eq. 38/B5 per the Erratum; total watts P_total = 4π r² P_OUT = I_pk² Z0/(8π) is DERIVED / ASSUMPTION, code name P_rad; I = peak, ASSUMPTION confirmed 2026-09-30; changed 2026-09-29; was I_pk² Z0/(4π): 2.127e-3 and 3.077e-2 / 9.197e-2 / 1.739e-1). **The three PNG maps in this folder were exported with the old form and are 3.01 dB high until re-exported from Mathematica (owed).**

HYP / illustrative isotropic E∥≈√(S·Z0). Style nod to US 9,306,527 B1 FIG. 2B; geometry is LAB Keyport sleeve + KB spheres (not patent skirt+monopole).

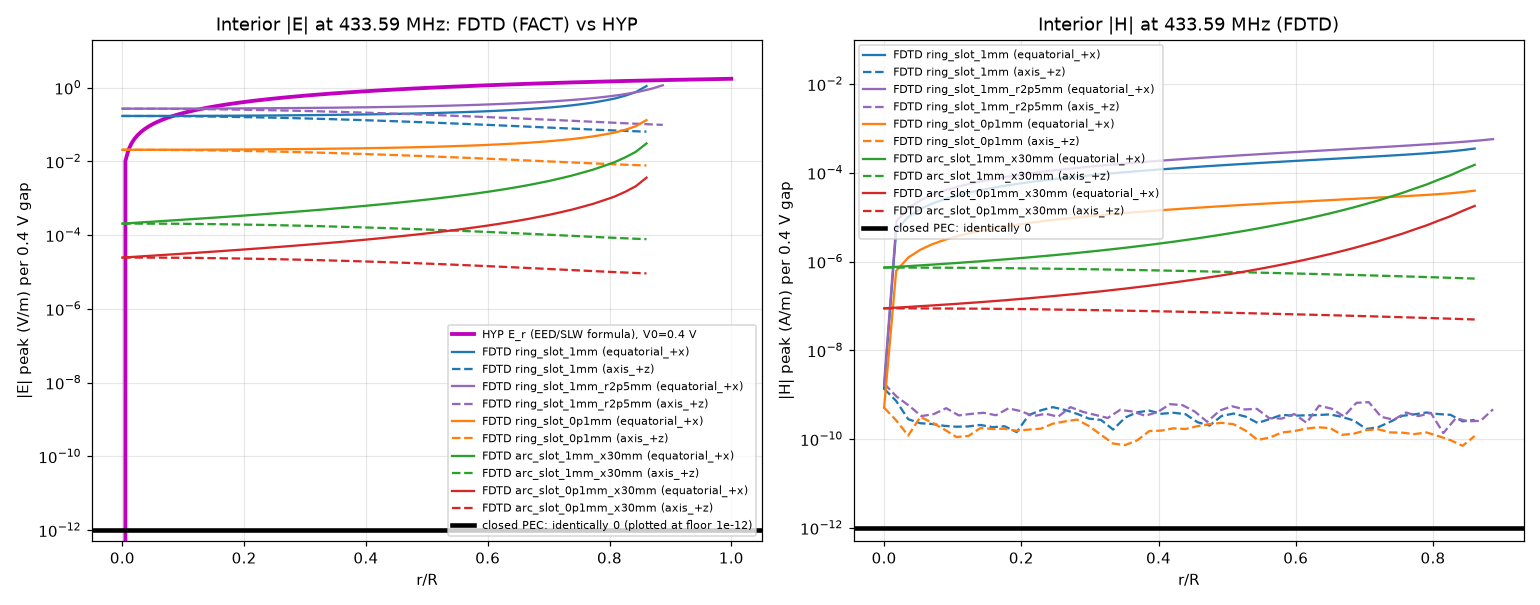
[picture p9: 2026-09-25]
img/fx1/interior_leakage_433MHz.png

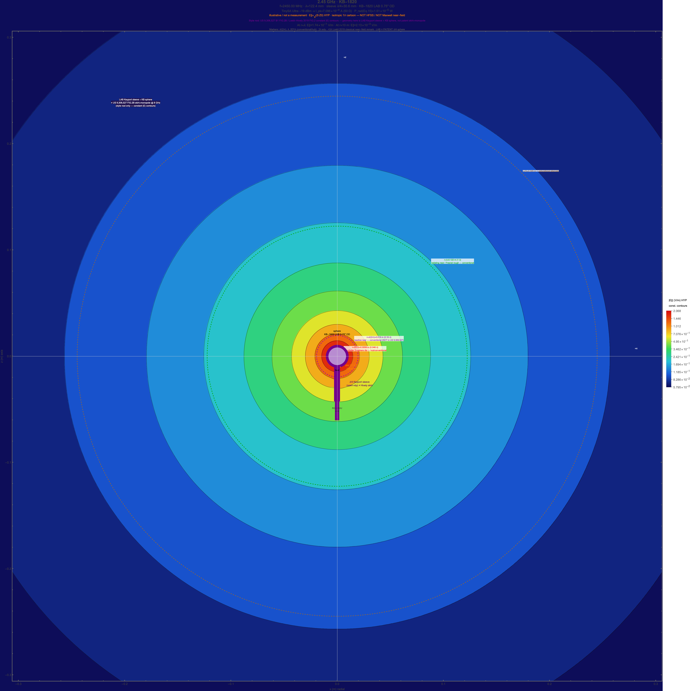
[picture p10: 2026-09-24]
img/efield/efield_2450MHz_KB1820.png

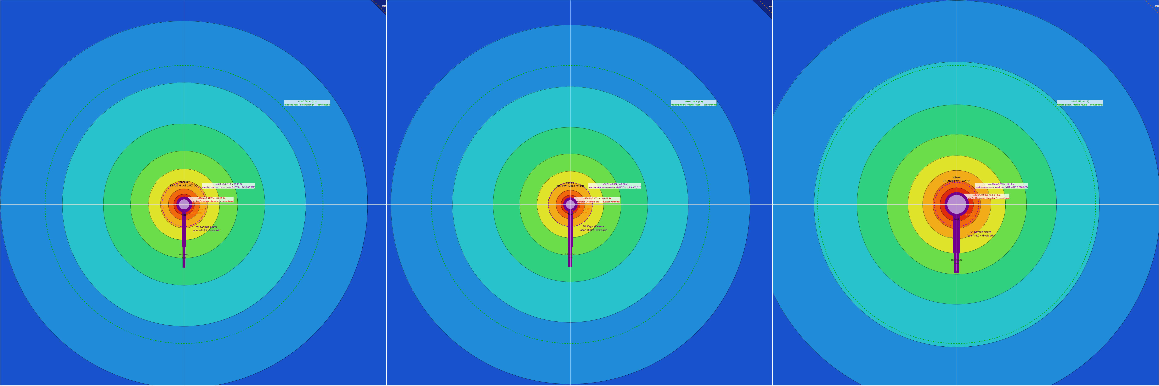
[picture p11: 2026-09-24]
img/efield/efield_three_bands_combined.png

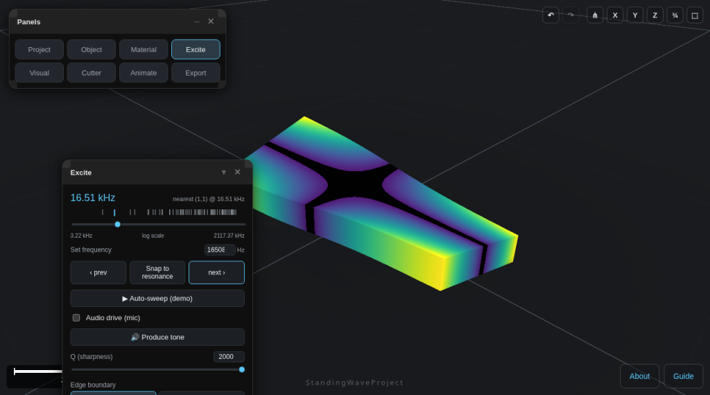
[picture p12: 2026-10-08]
img/exp-h/swp-steel-50x20x5-free-mode2.png

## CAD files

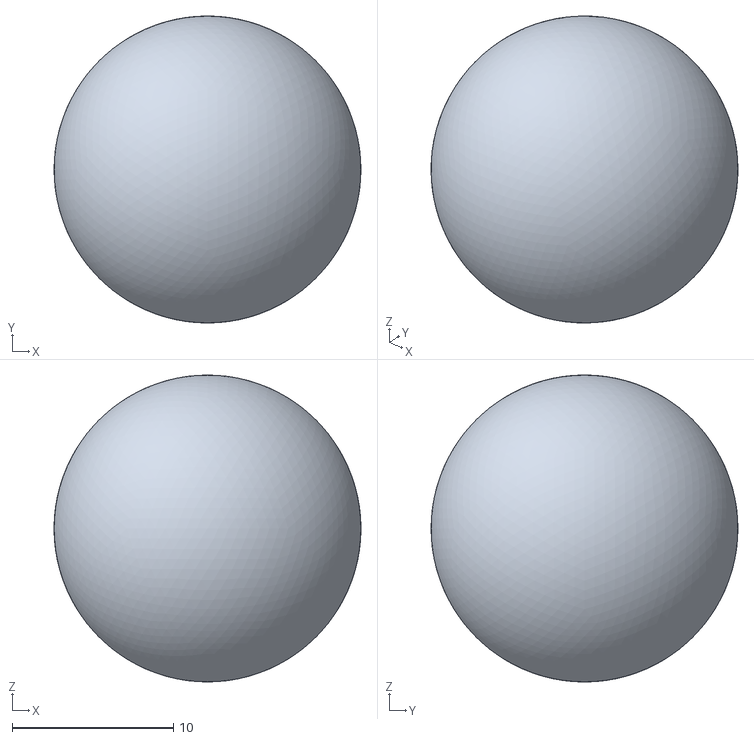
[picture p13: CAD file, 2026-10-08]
img/exp-h/kb1820-0.75in-closed-shell-1mm.stl
19.0 x 19.0 x 19.0

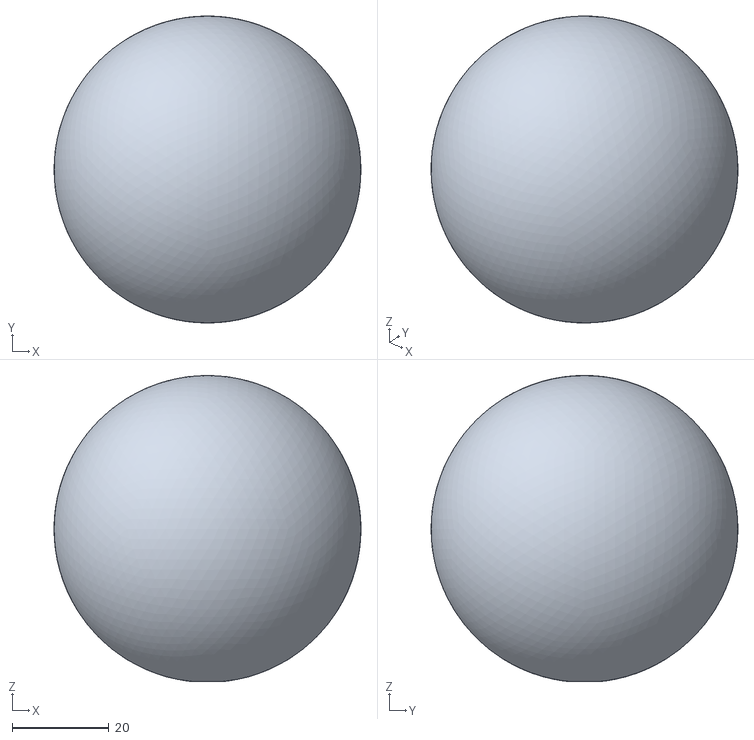
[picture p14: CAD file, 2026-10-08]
img/exp-h/kb2016-2.5in-shell-3.35mm-quarter-inch-hole.stl
63.5 x 63.5 x 63.3

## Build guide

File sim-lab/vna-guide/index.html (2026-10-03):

Skip to content

SLW Hub Britton · educational Menu

Simulation Lab · VNA guide for Steve · 2026-10-03 · vna-guide-v0.1

# Using a VNA on our kit: what others measured, and how to do it with Dan's NanoRFE VNA6000-A

A plain-English guide for Steve. Part 1 says what a VNA is. Part 2 tells you where to start. The tabs below hold the details: what other researchers measured with a VNA (with page and figure numbers), Dan's exact VNA and whether it reaches our frequencies, how it maps onto Experiments A, B and C, button-by-button steps from the maker's manual, and the manuals and videos.

MIXED ← Simulation Lab catalogue · Kit page: VNA6000-A · Three readings of SLW loss · Equation map

How to read the labels. FACT = stated in the named source (page or figure given). HYP = a hypothesis (for example an author's reading of what a signal means). Not established physics. IDEA = our suggestion for the bench; it is not from a source. NOT STATED = the source does not say. We do not guess. Numbers on this page are copied from the sources or from the maker's manual and data sheet; the only arithmetic we add is marked "our arithmetic".

## 1. What a VNA is, and why we use it

A VNA (vector network analyzer) is a test box for radio parts. It sends a small, known radio signal into a part and measures what happens to it. Think of it as a sound-and-echo tester:

- What bounces back (the echo) tells you how well the part is matched to the 50 Ω cable. That is called S11.
- What comes out the far end tells you how much signal the part lets through. That is called S21.
- "Vector" means it measures both the size of the signal (in dB) and its timing (phase), at many frequencies in one sweep.

Why we use it. Our experiments hunt very small signals. Before a run it helps to know that each antenna feed (sphere, stub, sleeve balun), cable and filter behaves the way you think at the frequency you care about. IDEA A bad connector or a mismatched feed can add or hide signal, and a VNA shows that in seconds.

How it differs from the TinySA Ultra. The TinySA is a spectrum analyzer: it listens to what is in the air or on a cable. The VNA tests a part: it sends its own signal and measures how the part passes or reflects it. The hub's kit page says the same: the TinySA is the on-air listener and generator, the VNA is the characterization tool (kit.html#vna6000).

### Words you will see (plain meanings)

DUT

Device under test: the part you are measuring (a sphere feed, a cable, a filter).

Port

An SMA connector on the VNA. The VNA6000 has two. Port 1 does the echo measurement (S11). Port 2 receives what passes through (S21). The manual calls them CH0 (reflection) and CH1 (through) (manual p.16).

50 Ω

The standard "size" of the cable and the ports. A part that is not 50 Ω at the test frequency sends some of the signal back as an echo.

dB (decibel)

A way to count ratios. Every 10 dB is a factor of 10 in power: −10 dB is one tenth, −20 dB is one hundredth, −3 dB is about half. A minus sign means "less than what went in".

S11 (reflection)

How much of the test signal comes back from the part, in dB. 0 dB means all of it comes back (nothing absorbed or radiated). The more negative, the better the match.

Return loss

The same echo measurement quoted as a positive number: a return loss of 20 dB is an S11 of −20 dB. Bigger is better.

SWR

Standing wave ratio: another way to say how big the echo is. 1.0 is perfect; bigger is worse. Radio people quote it for antennas.

S21 (transmission)

How much of the signal gets from port 1 through the part to port 2, in dB. 0 dB means all of it. −3 dB means about half. Often called insertion loss when the part is a filter or cable.

Smith chart

A round chart that plots a part's impedance (resistance plus reactance) as a dot. The centre is a perfect 50 Ω match; the outer edge is total echo. You can ignore it at first: the dB and SWR views are enough to start.

Sweep

The VNA steps from a start frequency to a stop frequency and plots the result across the whole range.

Calibration (open, short, load, thru)

Measuring parts whose behaviour is known so the VNA can subtract its own cable and connector errors. The place where you calibrate is the "reference plane", the spot the VNA treats as zero.

### Echo size in plain numbers

Textbook definitions, our arithmetic (SWR = (1+g)/(1−g) with g = 10^(−RL/20)). Use this to turn a return-loss reading into "how much power is coming back".

Return loss (dB) | S11 (dB) | Power reflected | Power accepted by the part | SWR
6 | −6 | 25.1 % | 74.9 % | 3.01
10 | −10 | 10.0 % | 90.0 % | 1.92
15 | −15 | 3.2 % | 96.8 % | 1.43
20 | −20 | 1.0 % | 99.0 % | 1.22
25 | −25 | 0.3 % | 99.7 % | 1.12
30 | −30 | 0.1 % | 99.9 % | 1.07

Cross-check from a source: Zimmerman's QEX article says a 3 dB pad gives a return loss of 6 dB, "for an SWR of 3" (QEX July/August 2011, p.32). That matches the first row. The hub has no stated pass mark for S11; Dan decides what is good enough. For scale, the sources report: a bias-tee with return loss better than 25 dB (MPLB p.650 footnote), a transmitting monopole at about −16 dB (CEM-R-46 p.23), a folded dipole at −15 dB (CEM-R-46 p.25), and Hively's balun at −22 dB in the patent and a 23 dB null in the paper (see the Hively rows below).

## 2. Where do I start?

Pick the box that matches what you want to do. Each one jumps to the right tab.

AI want to use the VNA nowButton-by-button: set the sweep, calibrate, measure S11 or S21, save. BIs this the right VNA, and does it reach our frequencies?Short answer: yes for 433.59 MHz, 1296 MHz and 2450 MHz. No for 8 GHz. CWhat do I measure on Experiment A, B or C?Sphere feed, stub or sleeve balun, cables, the filter, the rod cube, and the cage rule. DWhat did the other researchers do with a VNA?Zimmerman, Hively, Monstein and Wesley, and the rest, with page and figure numbers.

### First session in six lines (details in tab A)

1. Put the two SMA connector savers on the two ports and leave them on.
2. Open the menu (tap an empty spot on the screen) and set the sweep: STIMULUS → START and STOP.
3. Calibrate at the end of the cable you will measure through: CAL → RESET → CALIBRATE, then OPEN, SHORT, LOAD, DONE.
4. Connect the part. Show S11 as LOGMAG or SWR.
5. Move a marker to the dip (the best match) and write down the frequency and the dB.
6. Save the calibration (CAL → SAVE) and photograph the screen for your log.

Three rules before you plug anything in.

1. Limits. Never put more than +10 dBm (10 mW) of RF, or more than 5 V DC, into either port (manual p.3; data sheet p.2). Do not connect a transmitter, an amplifier output or a DC-biased tube straight to a port. IDEA If you are unsure of a source's level, put a fixed attenuator in line first.
2. The Faraday cage. No cable crosses the cage wall (Dan's standing rule). VNA measurements of parts happen outside the cage. Inside, only a battery-powered VNA with the USB cable unplugged, and never during a real listen: the VNA sends its own test signal (typically −10 dBm, data sheet p.3), which is far stronger than the faint signals we hunt. For the framing: the cage strips ordinary transverse-EM (TEM) noise (FACT); whether an SLW passes the cage wall is HYP. A VNA reading of a part does not test that either way.
3. Test signal on an antenna. A VNA sweep sends its test signal across the whole range you set. The hub says on-air work at 23 cm and 70 cm needs a licence. IDEA With an antenna connected, keep the sweep narrow and the level low, or use a dummy load, and check your local rules. This page is not legal advice.

## What others measured with a VNA

Short answer. Dan's hunch is right: the Zimmerman papers are the ones where a VNA is the main instrument, and S11 and S21 are the data. In our library that is three papers: Nikolova & Zimmerman (2007), Zimmerman's Modern Physics Letters B paper (2011) and his Journal of Applied Physics paper (2013). Zimmerman's QEX article is a how-to that talks about return loss and SWR but reports no VNA measurement. Hively's patent names a VNA model and the 2019 Hively & Loebl paper plots S21 and S12, but that paper's text does not name the instrument. Monstein & Wesley (2002) and Butterworth et al. (2013) did not use a VNA (a log detector with a voltmeter, and a USB spectrum analyzer).

### Summary table

Page numbers: "p." is the journal page where the journal's page numbers are printed on the copy we have; "PDF p." counts pages of the file. Figure and equation numbers are the papers' own. Scanned papers were read by text recognition (OCR), so those rows say "none found" rather than "none".

Source | VNA used? | What was measured | Where | Label
Nikolova & Zimmerman 2007 McMaster report CEM-R-46 | Yes. Advantest R3765CG VNA | Complex S21 (size and phase) from a dipole to a plasma-tube detector, 1.1 to 1.5 GHz, with the DC bias reversed; return loss of the transmitting monopole and folded dipole | PDF p.19 (Fig. 3); p.21 (Sec. V); p.22 (Eq. 70); p.23 to 26 (Figs. 7 to 10) | FACT measurements HYP "potential signal" reading
Zimmerman 2011 Mod. Phys. Lett. B 25(9) 649 | Yes. VNA, model NOT STATED | |S11|², 1 − |S11|² and |S21|² from 1280 to 1380 MHz through a 3 m circular waveguide, both bias polarities; copper-tube stand-in; complex S21 for free-space tests at 1.5, 6 and 25 m | p.650 (Fig. 1); p.653 (Sec. 3); p.654 (Fig. 5); p.655 (Eqs. 3a, 3b); p.658 | FACT setup and curves HYP Az / Ez split
Zimmerman 2013 J. Appl. Phys. 114, 044907 | Yes. "Network analyzer" and "vector network analyzer"; model NOT STATED | S21 magnitude and phase at 1300 MHz, 2 m, neon-bulb detector, bias current reversed; S21 of a bulb-in-front-of-reflector "gain antenna" | p.044907-3 (Figs. 4, 5); p.044907-4 (Fig. 7) | FACT plots HYP vector-potential reading
Zimmerman 2011 QEX July/August, pp.31 to 35 | No measurement. Design article | Explains return loss and SWR (a 3 dB pad gives 6 dB return loss, SWR 3); centred probe in a waveguide; bias-tee design built on a 50 Ω quarter-wave stub at 1296 MHz | p.32; pp.33 to 34 | FACT (text); HYP VP claims
Works & Works 2012 QEX July/August | No. SDR receiver S-meter | Antenna pairs about 15.2 m apart at 1296.1 MHz; EZNEC models. An isolator "provides low SWR" at the transmit mount | PDF pp.1 to 2 | FACT
Monstein & Wesley 2002 Europhys. Lett. 59(4) 514 | No. Log RF detector, voltmeter, ADC, GPS | Rod-cube transmission T(φ) at 433.59 MHz (instrument not stated); received power vs distance by the Rhine | pp.516 to 517 (Fig. 3, Eq. 9); p.518 (Rhine test and receiver) | FACT
Butterworth et al. 2013 J. Sci. Explor. 27(1) 13 | No. Signal Hound USB-SA44B spectrum analyzer | Repeat of M&W at 446 MHz with a UHF transceiver; no polarizer null with ball antennas | p.16 (Methods); p.17 | FACT
Hively patent US 9,306,527 B1 | Named: Agilent E5071C network analyzer (300 kHz to 20 GHz), "some implementations may include" | Return loss of the skirt balun antenna at 8 GHz (−22 dB single, −42 dB double); attenuation versus distance between two antennas on "port-1" and "port-2" | col. 7 (PDF p.14); cols. 9 to 10 (PDF p.15) | FACT as printed HYP SLW reading
Hively & Loebl 2019 Physics Essays 32(1) 112 | Plotted as S21 and S12; instrument NOT STATED in the text | Return-current attenuation of the balun (null near 8 GHz); SLW attenuation versus distance at 8.00 GHz in separate copper enclosures inside an anechoic chamber (S21 and S12 plots) | p.118 (Figs. 1, 2); p.119; p.120 (Figs. 3, 4); p.125 (Appendix D) | FACT as printed HYP SLW reading
Hively & Land IARD 2020 slides; JPCS 2021 | Slides repeat the S21 / S12 plot; the 2021 paper: none found | Slide 20 shows the same S21 / S12 attenuation plots (log-log slopes −2.6301 and −2.2273) | slide 20 | FACT
Navy Keyport patent US 12,525,711 B1 | None found. An "E-Field scanner" was used | Scanner images of radiation from the balun for two balun positions (Figs. 1B and 2B) | PDF p.11 (detailed description) | FACT
Other papers in the hub library | Chiao et al. arXiv 2013: yes (HP 8720C), but at 11.5 GHz. Others: none found | Chiao et al. 2013: S21 resonance of a TE112 cavity mode near 11.50 GHz, then a splitting of about 400 MHz with a wire inserted. Chiao 2007 only plans a network-analyzer study. The rest of the library (Tomilin 2021, Chiao 2017 and 2023, the NASA report, Hubler 2023, Hively 2026, Yue 2021, US 12,562,930 and others): none found | Chiao 2013 PDF p.9 | FACT

"None found" for Hively & Land 2021, the Keyport patent and the other library papers means a text search of the copies we hold found no VNA, S11 or S21 measurement. It is not proof the authors did not use one.

### Details by paper

Nikolova & Zimmerman 2007 (CEM-R-46): VNA used, S21 and return loss

- FACT Setup (Fig. 3, PDF p.19). A transmit folded dipole, a propagation path, a fluorescent U-tube detector, a bias-tee, a current-regulated supply, a 30 dB amplifier in the RF path, and a vector network analyzer. A 50 Ω coax carries both the RF to the VNA port and the DC bias, separated by the bias-tee (PDF p.21).
- FACT Instrument. "an Advantest VNA R3765CG" (PDF p.21). VNA output power "set at 5 dBm" (PDF p.20).
- FACT What they did with it. Measured the complex S21 with a positive and then a negative DC bias, and formed the sum and difference: S_A = 0.5 (S21+ − S21−) and S(E,H) = 0.5 (S21+ + S21−) (Eq. 70, PDF p.22). They state that a VNA is "a phase-coherent system" that allows this.
- FACT Frequencies and results. 1.1 to 1.5 GHz. In a compact anechoic chamber at 1.2 to 1.5 m with no amplifier, the transmitting monopole's "return loss is minimum at 1.22 GHz and is about −16 dB" (PDF p.23). Magnitude and phase of S21 at 1.2 m are in Figs. 7 and 8 (PDF p.23 to 24). The measured S_A at 1.3 GHz and 1.2 m is −59.7 dB against a calculated −56.7 dB (PDF p.24).
- FACT In the open. A folded dipole fed through a 4:1 balun, "reflection loss is −15 dB at about 1.21 GHz", with an amplifier of 29 to 30 dB gain and data every 25 cm (Fig. 10, PDF pp.25 to 26).
- FACT Balun remark. Power-type signals "may be picked up by the feed coaxial lines … if the feed baluns are not well tuned" (PDF p.22). That is the reason to check a balun with a VNA.
- FACT Their estimate for 3 m is an S21 of about −65 dB, "well above the noise level of the system" (PDF p.21).
- HYP The authors read the bias-dependent part of S21 as a "potential signal" (vector potential). That interpretation is theirs and is not settled physics.

Zimmerman 2011 (MPLB): VNA used, S11 and S21 across 1280 to 1380 MHz

- FACT Setup (Fig. 1, p.650). A 3 m long, 17.78 cm diameter circular copper waveguide excited by a centred coaxial probe at the head. A folded mercury-vapour plasma tube (a compact fluorescent lamp) at the far end is the detector. VNA port 1 feeds the probe. The tube connects through a bias-tee to VNA port 2 (p.650). The DC bias polarity is reversed with a switch.
- FACT Calibration. "The experimental data are taken with a full 2-port calibration of the VNA and cables with reference loads, shorts, and opens traceable to NIST" (p.653).
- FACT What was plotted (Fig. 5a, p.654). |S11|² at the top, the calculated (1 − |S11|²) below it, and |S21|² at the bottom for both bias polarities, 1280 to 1380 MHz. When losses are present, (1 − |S11|²) exceeds |S21|². The negative-bias S21 has a mean of −16.5 dB ± 1.0 dB; the positive-bias curve is some 5 dB lower; both S21 curves are anti-correlated with (1 − |S11|²) (p.653).
- FACT Control. A copper mock-up of the tube was measured instead (Fig. 5b, 5c): its S21 does not split with bias current and tracks (1 − |S11|²) (p.653). This is a good habit: swap in a dummy and see what the VNA shows.
- FACT Free-space tests. Open-ended waveguides at 1.5, 6 and 25 m with phase data; the VNA output was +10 dBm for the waveguide test and the 1.5 m test, and an external amplifier at +20 dBm was used for 6 and 25 m (pp.655 to 658). The conclusion lists that A and E "may be individually calculated from amplitude/phase data collected with a VNA" (Eqs. 3a, 3b; p.658).
- FACT A bias-tee used here had "return loss … < −25 dB from 1 GHz to 1.48 GHz" and an RF insertion loss of −0.04 dB (footnote, p.650).
- HYP The split into Az and Ez components, and the Aharonov-Bohm reading, are the author's interpretation.
- Copy note. The hub's library copy of this paper carries the publisher's "re-use … strictly not permitted" stamp, so this guide links the publisher's DOI page and not the PDF.

Zimmerman 2013 (J. Appl. Phys.): network analyzer used, S21 magnitude and phase at 1300 MHz

- FACT Setup (Figs. 1 to 3, pp.044907-2 and -3). A transmitting monopole with a quarter-wave-radius reflector at 1300 MHz, aimed at an NE-2 neon bulb 2 m away. DC bias reaches the bulb through a bias-tee with 0.04 dB insertion loss and more than 25 dB isolation.
- FACT How the VNA was used. "The monopole is driven with 1 mW of RF power (0 dBm). With this power level as a reference, the network analyzer display may be read directly in dBm" (p.044907-3).
- FACT Fig. 4: S21 for both bias polarities (bias current 8.8 mA). The two traces differ by more than 10 dB at the centre frequency; the mean received power is −52 dBm (p.044907-3).
- FACT Fig. 5: phase. The RF phase reverses when the bias current is reversed. The plot is 360 degrees per division, centre 1300 MHz, span 50 MHz, with "a port extension of 73 ns" on port 1 to "unwind" the phase (p.044907-3).
- FACT Fig. 7: the gain antenna. With the bulb a quarter wave in front of a planar reflector, the VNA S21 plot (Fig. 7) shows about a 6 dB improvement (p.044907-4).
- FACT The paper says signal levels were "confirmed for R = 2, 50, and 100 meters" (p.044907-4). Which instrument was used at 50 and 100 m is NOT STATED.
- FACT A worked mismatch example (not a VNA reading): a bulb of 8522 Ω on a 50 Ω cable has a voltage reflection coefficient of 0.9885 (Eq. 14, p.044907-2). That is the same idea as S11, taken to the extreme.
- HYP The paper reads the phase reversal as "a cardinal sign of vector potential detection". That is the author's claim.
- Copy note. AIP's copyright notice is stamped on each page, so this guide links the publisher's DOI page and not the hub copy.

Zimmerman 2011 (QEX): a how-to, no VNA measurement

- FACT A 3 dB pad on the coax to the waveguide "will provide a return loss of 6 dB for an SWR of 3" (p.32). The text warns that a zero-ohm load "will yield an infinite SWR" on the transmitter's cable, so a pad (or a circulator) protects the transmitter (p.32).
- FACT The lamp tube carries the received current "similar to a parallel transmission line" out to a coax and on to the receiver (p.31). The MPLB paper puts a number on that line: 125 Ω, against the 50 Ω cable, so the mismatch reflection is (50 − 125)/(50 + 125) = −0.43 (MPLB p.653).
- FACT A bias-tee design at 1296 MHz built on a 50 Ω quarter-wave stub with two 1000 pF capacitors, one to block DC from the receiver line and one to bypass the stub's cold end (p.34). About −400 V DC is momentarily needed to ignite the tube (p.33). The text says the report is based on the MPLB paper.
- No S-parameter measurement is reported. Scanned copy; read by OCR.

Works & Works 2012 (QEX): no VNA

- FACT Test range at 1296.1 MHz with antenna mounts 15.2 m apart; a Flex-3000 SDR receiver with S-meter averaging; 21.6 dBm transmit power available; over 500 measurements; EZNEC models (PDF pp.1 to 2).
- FACT "An isolator at the transmit mount provides low SWR on the transmit feed line" (PDF p.1). No VNA or S11 is reported.

Monstein & Wesley 2002 and Butterworth et al. 2013: no VNA

- FACT M&W 2002: the rod-cube test (Fig. 3) is a measured transmission coefficient T at 433.59 MHz against the angle φ, with the curve T = exp[−κ cos²φ], κ = 4.4 (Eq. 9; pp.516 to 517). The instrument for Fig. 3 is NOT STATED.
- FACT M&W 2002 Rhine test: a Trio TR-9500 transmitter on a 12 V car battery, triggered by a 1 s oscillator so each cycle includes a quiet reference; receiver = ball antenna + LNA435 low-noise amplifier + AD8307 logarithmic RF detector + digital voltmeter, with a PICO-ADC10 analog-to-digital converter to a PC and GPS positions (p.518).
- FACT Butterworth et al. 2013: Realistic HTX-404 UHF transceiver at 446 MHz; received signal "analyzed using a Signal Hound USB-SA44B Signal Analyzer" (p.16). They did not see the M&W polarizer null with ball antennas; the arrays did act as polarizers with simple half-wave dipoles (p.17).
- IDEA Our arithmetic from M&W's own formula: at φ = 0 the model gives T = e^(−4.4) = 0.0123, which is −19.1 dB relative to no loss. That is the size of drop to look for if you repeat the rod-cube test with the VNA (see the Experiments tab). Butterworth's result is a reason to keep a dipole-antenna control.
- Hively & Loebl 2019 (Appendix D, pp.124 to 125) prefer a network analyzer's phase-locked signal to M&W's custom transmitter and receiver. That is their view of the method (HYP).

Hively patent (US 9,306,527 B1) and Hively & Loebl 2019: S-parameters at 8 GHz

- FACT Patent, col. 7 (PDF p.14). "Some implementations may include an Agilent Technologies E5071C network analyzer (300 kHz to 20 GHz)." Transmitting and receiving antennas "may be identical, because the reciprocity theorem guarantees" the transmitter can also act as a receiver. This VNA is a bench instrument; Dan's VNA6000-A tops out at 6 GHz, below the 8 GHz these tests used.
- FACT Balun numbers as printed. Patent col. 7: "The measured return loss was −22 dB for a single skirt balun … and −42 dB for a double balun (not shown)", and an antenna-balun impedance of 49.76 − 0.24j Ω against the 50 Ω source. The 2019 paper (p.118 and Fig. 3, p.120) shows the measured balun return-current attenuation with a shallow null of 23 dB at 8.00 GHz, against a simulated null of 49 dB at 7.94 GHz, and gives 42 dB for a double balun (not shown). The two documents state this differently (22 versus 23 dB). HYP They may describe the same measurement; we have not reconciled them.
- FACT Attenuation versus distance. Patent cols. 9 to 10 and 2019 Fig. 4 (p.120) show two facing antennas at 8.00 GHz, each inside its own copper pipe enclosure, inside an anechoic Faraday chamber ("90 dB isolation", p.119). The patent labels the antennas "port-1" and "port-2"; the paper labels the plots S21 and S12. The instrument is not named in the paper's text. The test layout uses "directional couplers" described as 45 dB isolators (p.118).
- FACT The paper reports "an attenuation between 115 dB at r = 2 cm separation and 137 dB at r = 30 cm" for that test (p.120). Any comparison with an ordinary skin-depth shielding estimate is transverse-EM reasoning, NOT applicable under the SLW hypothesis, so this guide makes none.
- HYP Whether the SLW passes the enclosures is the paper's claim, not an established result.

What the VNA papers teach us for our bench

1. FACT They measured S11 and S21 together and compared them: (1 − |S11|²) against |S21|² (MPLB Fig. 5). IDEA For each antenna pair, record both.
2. FACT They calibrated with the cables on (MPLB p.653) and used a port extension to straighten out phase (JAP Fig. 5). The VNA6000 manual says a saved calibration also keeps the "electrical delay" setting (manual p.22).
3. FACT They used a dummy (a copper stand-in for the plasma tube) as a control (MPLB Fig. 5b, 5c).
4. FACT Their drive levels were higher than Dan's VNA: +10 dBm (MPLB), 5 dBm (CEM-R-46), 0 dBm (JAP), against a VNA6000 test-port output of about −10 dBm typical (data sheet p.3). Our arithmetic: that is 10 to 20 dB lower. The S21 reading in dB does not depend on the drive level, but the noise floor eats more of a weak signal. The data sheet gives a 95 dB transmission dynamic range for the VNA6000-A at 200 MHz to 5.8 GHz (data sheet p.4, measured with IF bandwidth 0.8 kHz and 10 averages), so S21 values of −45 to −70 dB, as in CEM-R-46, should sit above the floor (our arithmetic, not a test). IDEA Use a narrow IF bandwidth or averaging on weak S21 readings.
5. FACT DC bias needs a bias-tee. All three Zimmerman VNA papers feed the DC bias to the plasma tube or bulb through a bias-tee. The VNA6000 ports take at most 5 V DC (data sheet p.2), and Zimmerman's QEX article says about −400 V DC is momentarily needed to ignite the tube (p.33). Never connect a biased tube straight to a VNA port.

## Dan's VNA: the NanoRFE VNA6000-A

Which one is it? The hub's kit page records it as the NanoRFE VNA6000-A (kit.html#vna6000). The maker (NanoRFE) sells the VNA6000 as a two-port, 6 GHz instrument in two versions, A and B. It is a pocket "NanoVNA family" instrument with a touch screen. It is not a Mini-VNA. FACT from the maker's data sheet and product page; FACT from the hub for "-A".

### Does it reach our frequencies?

Maker's stated range: 50 kHz to 6 GHz (data sheet p.3, "Frequency range").

Where | Frequency | In range? | Comment
Experiment B | 433.59 MHz | YES | Comfortably inside. Good for the KB-2016 balls and the 346 mm rods.
Experiment A (Dan sometimes says "1.3 GHz") | 1296 MHz | YES | Inside. The Zimmerman papers worked at 1.1 to 1.5 GHz, so you can compare your plots with theirs.
Experiment G | 1057.8 MHz | YES | Inside.
Magnetron / dipole work | 2450 MHz (2.45 GHz) | YES | Inside. The maker quotes its dynamic range at 2.5 GHz (95 dB for the A version). Accuracy is better with a good calibration kit, and the maker warns that clones are inaccurate above 1 GHz, so check the unit is genuine.
Hively's lab tests | 8 GHz | NO | Above the 6 GHz limit. Hively's own bench used a different, much bigger instrument. We cannot repeat his 8 GHz work with this VNA.
Chiao's cavity | 11.5 GHz | NO | Above the limit.

Our three working frequencies all fall inside the range, so 2.45 GHz does not exceed it. This verdict is from the maker's published range; it has not been checked on Dan's own unit.

### The numbers worth knowing (from the maker's data sheet, revision dated 2022/08)

Ports | Two SMA female ports, 50 Ω (data sheet p.3). You need SMA male connectors or adapters on whatever you test.
What it measures | A "T/R" type: S11 and S21 directly. To get S22 and S12 you turn the part around (data sheet p.3; manual p.3).
Test signal | About −10 dBm per port, typical (data sheet p.3). That is 0.1 mW.
Do-not-exceed | +10 dBm RF and 5 V DC at either port (data sheet p.2; manual p.3).
Dynamic range (S21) | VNA6000-A: 95 dB from 200 MHz to 5.8 GHz, 90 dB at 5 MHz. VNA6000-B: 110 dB (data sheet p.4; measured calibrated, 0.8 kHz IF bandwidth, 10 averages). Anything weaker than the floor shows only noise. The letter on the unit's label tells you which one you have.
Sweep points | 10 to 4096 on the device; more with a PC (data sheet p.3).
IF bandwidth | 0.8, 1.7, 3.1, 4.7, 6.2 or 10 kHz. Narrower is slower but quieter (data sheet p.3).
Biggest signal it can measure | 0 dB. An amplifier with gain needs an attenuator in line that is at least as big as its gain, or the reading is wrong. Dan's low-noise amplifiers (about 21 dB gain) need a 20 dB or bigger pad on the output side when you test them. IDEA (the 0 dB limit is the data sheet's; the pad advice is ours).
Power and battery | USB 5 V supply, or an internal 18650 lithium cell (flat-top, unprotected only; button-top or protected cells do not fit). It also runs from USB with no battery (manual p.4). Four red LEDs show charge (manual p.6).
Software | Optional PC program "VNA View" (a NanoVNA-QT variant) over USB; the maker lists NanoVNA-Saver also (see Links).
Weight and weather | About 300 g; works 0 to 45 °C (data sheet).

### What should be in the box (the two lists disagree: check yours)

- Manual p.4 says: the VNA, a USB cable, a stylus, two SMA connector savers, calibration standards (the manual says "5" but names a Short, an Open and 2 Loads, which is four; count what is in yours) and optionally two SS405 / SS402 SMA male-male cables.
- The maker's product page also lists a Thru and two 30 cm SS405 cables.
- Check yours against both lists. If there is no Thru in the kit, you can still do the one-port (S11) calibration; the two-port S21 calibration works best with a Thru, and a short SMA female-to-female adapter can stand in for one. IDEA

### How it complements the TinySA Ultra

| TinySA Ultra | VNA6000-A
What it is | Spectrum analyzer: it listens, and shows how much signal there is at each frequency | Network analyzer: it sends a test signal and shows how a part passes or reflects it
Question it answers | "What is coming in on this cable or antenna?" | "How well does this part pass or reflect, from 50 kHz to 6 GHz?"
Use on the bench | Watch the real signal during a run | Check the parts before the run: match, cable loss, filter shape
During a sealed run | Used as the hub describes | Off. Its test signal would swamp the faint signals we are after

To confirm on the unit (not verifiable from our files).

1. The label on the back: does it say VNA6000-A? (The hub says A; the label is the proof.)
2. Firmware: CONFIG → VERSION. The manual is dated 2022/11, and the maker's pages show newer firmware, so a menu on your unit may be named differently from this guide.
3. Calibration kit contents: is there a Thru or a second cable? (see the two lists above)
4. Is a battery installed? The manual shows how to tell from the LEDs (p.6).

If any of these differ from what this page says, trust the unit and the maker's manual, and tell Dan.

## What to measure on Experiments A, B and C

Everything in the recipes below is an IDEA of ours: a way to apply the VNA to the hub's kit, patterned on what the sources did. The hub's kit page lists these same uses (S11 of the sphere feed, S21 of the 23 cm filter, a TDR check of cable pigtails, an optional stub S11). Keep the sources' HYP framing: a good S11 only tells you a part is a decent 50 Ω match; it does not test the SLW hypothesis.

Experiment | Frequency | Hardware (hub pages) | Sweep to try first
Experiment A | 1296 MHz | K-Mac KB-1820 ¾″ hollow aluminum sphere fed by an Amphenol 901-9875 SMA bulkhead (small coax into the ball, outer conductor as shield); 23 cm band-pass filter in the transmit chain; RG-405 sleeve stub (archived in the setup page); mesh tents; TinySA Ultra | 1100 to 1500 MHz (the N&Z band), then 1250 to 1350 MHz
Experiment B | 433.59 MHz | KB-2016 2.50″ balls with the 901-9875 feed, no balun, two SMA male-male RG-316 jumpers, 3×3 array of brass half-wave rods (346 mm) for the polarizer cube | 400 to 470 MHz (a video below uses 420 to 455)
Experiment C | 1296 MHz RF arm, plus the optical arm | The RF arm re-uses Experiment A practice (stub, sphere, bifilar); the photomultiplier / optical arm is not a VNA job | As Experiment A

### Recipe 1: S11 of a sphere and its feed (Experiments A and B)

1. What it tells you: how much of the test signal the ball and its feed send back. A dip at your frequency means the ball accepts power there. A ball with a short-circuited or open feed shows almost 0 dB everywhere. IDEA
2. Calibrate at the end of the cable you will use (see the Step-by-step tab), with the sweep window from the table above.
3. Connect the sphere's SMA bulkhead to the cable end. Show S11 as LOGMAG and again as SWR.
4. Touch test: hold the ball by hand and by its stand, and move the cable. A reading that jumps means the outer conductor of the cable is carrying signal. That is the same worry N&Z (2007, PDF p.22) raise about badly tuned feed baluns. IDEA
5. Control: repeat with the ball replaced by a 50 Ω load (a dummy), as Zimmerman did with his copper stand-in (MPLB Fig. 5b, 5c). If the readings look alike, the ball is not telling you anything yet.
6. Log: frequency of the dip, depth in dB, SWR at your operating frequency, the cable, and a photo of the screen.

### Recipe 2: the sphere with its stub or sleeve balun (Experiment A, C)

1. Measure the sphere alone (Recipe 1), then the sphere with the sleeve stub / sleeve balun fitted, with the same calibration. Overlay the two saved traces.
2. What to look for: whether the match moves and whether the cable-touch jump goes away. A sleeve balun's job is to keep signal off the outside of the coax. IDEA See the hub's sleeve balun page for the geometry.
3. Source analogs: Hively's patent reports a balun return loss of −22 dB (single) and −42 dB (double) at 8 GHz (col. 7; FACT as printed), and N&Z measured a folded dipole with a 4:1 balun at −15 dB at about 1.21 GHz (PDF p.25). Neither number is a target for your hardware; they only show what the others measured.

### Recipe 3: cables, pigtails and connectors

1. Cable loss (S21): connect the cable between port 1 and port 2 (Thru calibrated). Read S21 at your frequency. A good short jumper reads a small negative number of dB. A sudden worse reading usually means a bad crimp or connector.
2. Cable fault finding (time domain): the manual covers a time-domain (TDR) mode that shows reflections against distance (manual pp.18 to 21). Enter the cable's velocity factor as a whole number such as 67, not 0.67 (manual pp.18 to 21). Use the RG-316 data sheet value for your cable. The hub's kit page lists this as a use of the VNA.
3. Hints: SMA connectors want a snug finger-tight turn, then a gentle nudge with an SMA wrench (do not over-tighten and do not twist the cable). Keep the cable still while the sweep runs, and keep the same cable from calibration to measurement. Use the supplied connector savers on the VNA ports, so wear happens on a cheap adapter. Avoid tight bends in the RG-316. IDEA (manual p.4 introduces the connector savers; the torque and handling hints are our general practice, not from the manual).

### Recipe 4: the 23 cm band-pass filter (Experiment A) — S21

1. Calibrate both ports with the Thru, sweep 1000 to 1600 MHz.
2. Connect the filter between port 1 and port 2. Show S21 as LOGMAG.
3. Read the pass band: the loss at 1296 MHz, and how fast it drops each side. The filter's data sheet gives the maker's expected curve; compare. IDEA
4. This is the same kind of measurement as the low-pass filter video in the Links tab.

### Recipe 5: the rod polarizer cube (Experiment B) — S21 and loading

The hub says the polarizer cube is not by itself a two-port part, so the following are our suggestions, not something a source did with a VNA. (Monstein & Wesley did not use a VNA; their measurement instrument for the cube curve is not stated.)

1. Path S21: put the transmit ball on port 1 and the receive ball on port 2, with the cube between them at a fixed spacing. Calibrate with a Thru at the cable ends. Record S21 at 433.59 MHz at each cube rotation angle φ. IDEA
2. What to compare: M&W's formula gives T = exp[−4.4 cos²φ] (Eq. 9, p.516); our arithmetic: that is a 19.1 dB drop at φ = 0. Butterworth et al. (2013) did not see that null with ball antennas but did with half-wave dipoles (p.17). Whatever you see, log it as measured, and say which antennas were used.
3. Loading S11: measure the transmit ball's S11 with the cube removed, then in place at each angle, to see whether the cube pulls the match around. IDEA
4. Keep the room fixed. People moving, metal tables and the cables will change an air path S21 by several dB. Do all angles in one sitting with the cables taped down.
5. Rule: This is a bench job outside the cage, with the VNA at a low sweep rate. The cage itself is not on this list.

### The cage rule, again

- No cable crosses the Faraday cage wall (Dan's standing rule). Parts are measured outside. If a measurement must be done inside, it is battery or optical only, with no cable through the wall, and the VNA off during any real listen.
- Cage framing: it strips ordinary transverse-EM noise (FACT); whether an SLW passes the wall is HYP. The hub's submarine page lists a "seam-coupon S21 with the NanoRFE VNA outside the cage" (tagged transverse-EM reasoning); keep that tag if you do it.
- Under the SLW hypothesis we do not argue from skin depth or permeability. Any such reasoning carries the tag "transverse-EM reasoning, NOT applicable under the SLW hypothesis".

### What a VNA in air cannot tell you about the Joule term

The hub's loss-modes page (sim-lab/loss-modes) compares three readings of SLW loss: the Joule-literal default, the erratum's "no loss", and a charge-relaxation-only hypothesis. For a path through air all three give the same prediction, so an S21 in air cannot decide between them. They differ only in a conductive medium such as seawater (see that page). The Joule-literal reading remains the hub's default.

### Parts list for a VNA session

Item | Qty | Note
NanoRFE VNA6000-A with USB cable and stylus | 1 | Charged, or on USB power
SMA connector savers (supplied) | 2 | Leave on the ports
Calibration standards: Open, Short, Load (and Thru if supplied) | 1 each; 2 Loads in the kit | SMA male, per the manual's list
SMA male-male cables for test leads | 2 | Same cables for calibration and measurement; RG-316 jumpers from the hub kit work
SMA female-female adapter | 1 or 2 | For a Thru, and for jumpering cables
SMA wrench (small, 5/16″) | 1 | Gentle torque only
Fixed 20 dB SMA attenuator | 1 | For amplifier tests only; not supplied; do not buy until you need it
Dummy 50 Ω load (a spare from the kit) | 1 | The control for every antenna test
Notebook and phone camera | 1 | Log the settings and photograph the screen

SMA wrench size is our general knowledge; it is not from the manual.

## Button-by-button with the VNA6000-A

Where these steps come from. The NanoRFE VNA6000 User Manual, edition 2022/11 (30 pages). Every step below names its manual page. Menu names are written the way the manual writes them, in capitals, with an arrow between menu and item (for example CAL → RESET). Steps tagged IDEA are our advice, not the manual's. Your unit's firmware may be newer than the manual, so a menu name may differ; the "Not verified" list at the bottom says what the manual does not cover.

### A. Set the frequency range (manual pp.11 to 12)

1. Open the menu. Tap an empty spot on the touch screen (not on a marker), or press the ENTER button (p.7). You see: a menu list with DISPLAY, MARKER, STIMULUS, CAL, RECALL, CONFIG and CLOSE.
2. Tap STIMULUS → START, type the number on the on-screen keypad, then tap the unit key (for example M for MHz). The unit key multiplies your number and ends the entry (p.8). Then STIMULUS → STOP the same way.
3. Or use the middle and width instead: STIMULUS → CENTER and STIMULUS → SPAN (p.12).
4. Suggested windows IDEA: Experiment A: START 1100 MHz, STOP 1500 MHz. Experiment B: START 400 MHz, STOP 470 MHz.
5. Pause the sweep with STIMULUS → PAUSE SWEEP if you want a frozen picture (p.12). Turn it off again to keep measuring.

### B. Calibrate (manual pp.13 to 14)

Always set the frequency range first. If you change the range afterwards, the old calibration is only stretched to fit and the manual says it "may degrade accuracy", so calibrate again (p.13).

Choose where the reference plane goes. Calibrate at the VNA ports (p.13) if you will plug the part straight in. Calibrate at the end of your cable (p.14) if a test cable will go between the VNA and the part. For our work you will nearly always want the cable version: keep the same cable on for calibration and measurement.

1. Clear any old calibration: CAL → RESET, then → CALIBRATE (p.14, step 1).
2. Attach your SMA cable to port 1 (p.14, step 2). Skip this step if you are calibrating at the port itself.
3. Put a LOAD on port 2 (p.14, step 3).
4. OPEN: screw the OPEN standard onto the end of the port-1 cable and tap → OPEN. Wait until the menu item lights up (highlights).
5. SHORT: swap in the SHORT standard, tap → SHORT, wait for the highlight.
6. LOAD: swap in the second LOAD standard, tap → LOAD, wait for the highlight. The manual says you need not wait for the plot to redraw before tapping the next item: each tap does one full sweep with extra averaging, and the highlight tells you it is done (p.14).
7. (Only for S21 / through measurements) THRU: connect a second cable to port 2 and join the two cable ends with the THRU standard, then tap → THRU (p.14, steps 7 and 8). Then take the THRU out.
8. Tap → DONE. You see: "Cx" on the left side of the screen, meaning calibration is active (p.13).
9. Save it: CAL → SAVE → SAVE 0 (p.13 and p.22). IDEA Use slot 0; the manual says "0 to 6" in one place (p.13) and gives a different count on p.22, so we do not rely on higher slots.
10. Check it: CAL → CORRECTION shows whether the correction is on (p.22). IDEA With the open standard on the cable end, S11 should read close to 0 dB across the range; with the load on, S11 should be very low. If not, redo the steps.
11. To restore later: CAL → RECALL → RECALL 0 (p.22). Remember it only fits the range that was in use when you saved it.

### C. Measure S11 (reflection) (manual pp.15 to 17)

1. Connect the part to the port-1 cable end. Leave port 2 on its LOAD.
2. Pick the channel: DISPLAY → CHANNEL → CH0 REFLECT. This is S11 (p.16).
3. Pick how to draw it: DISPLAY → FORMAT → LOGMAG for a dB plot, or SWR for a standing-wave plot. The list is LOGMAG, PHASE, DELAY, SMITH, SWR, POLAR, LINEAR, REAL, IMAG, RESISTANCE, REACTANCE (p.16).
4. Several views at once: up to four traces: DISPLAY → TRACE → TRACE n. Tapping the active trace turns it off (p.15). IDEA Trace 0: S11 LOGMAG; trace 1: S11 SWR; trace 2: the saved no-ball control, if you have one.
5. Read a number: MARKER → SELECT MARKER → MARKER n, then drag it along the trace (p.17). Under MARKER → OPERATIONS you can send the marker to START, STOP, CENTER or SPAN (p.17). IDEA Slide the marker to the lowest point of the dip and write down the frequency and the dB.
6. Save a picture of the plot: the manual does not describe a screenshot function on the device (see the "Not verified" list), so photograph the screen with your phone and note the calibration slot and sweep range.

### D. Measure S21 (through / loss) (manual pp.14, 16)

1. Calibrate with the THRU (Section B, steps 7 and 8) so port 2 is included.
2. Connect the part between the cable ends: port-1 cable, then the part (filter, cable, attenuator), then port-2 cable.
3. Pick the channel: DISPLAY → CHANNEL → CH1 THROUGH. This is S21 (p.16).
4. Format: DISPLAY → FORMAT → LOGMAG (p.16). Put a marker at your frequency to read the loss in dB.
5. Check the reading is not noise. A trace that is flat and jagged near −90 dB or lower is the instrument's floor (the data sheet gives 95 dB of dynamic range for the A model, p.4). IDEA Do not read anything near the floor as a result.

### E. Cable test in the time domain (manual pp.18 to 21)

The VNA turns its frequency sweep into a distance picture (the manual calls it simulated TDR, time-domain reflectometry). Longer measurable distance needs a lower stop frequency; sharper distance accuracy needs a wider span (p.18).

1. Turn it on: DISPLAY → TRANSFORM → TRANSFORM ON (p.18; the manual's own text spells the menu "TRANSOFRM" in one place). When it is on, the item shows as white text on black and the plot shows time or distance instead of frequency.
2. For the "lowpass" style the manual says the start frequency must be 50 kHz, the stop frequency is set by how far you want to see, and the format can be REAL (p.19). The bandpass mode instead takes LINEAR, LOGMAG or SWR (p.18). Recalibrate for the range you choose.
3. Enter the velocity factor of the cable as a whole number, for example 67 and not 0.67 (p.21: "specify 67 for the VELOCITY FACTOR. Do not use the decimal point"). Set it under DISPLAY → TRANSFORM → VELOCITY FACTOR. Look up the value for your own cable; we do not give one here.
4. Choose a window: MINIMUM, NORMAL or MAXIMUM (p.21). MINIMUM gives the sharpest distance resolution, MAXIMUM the greatest dynamic range, NORMAL is in the middle (p.21). Start with NORMAL. IDEA
5. Read the plot: a bump at a distance shows a reflection there (a connector or a damaged spot).

### F. Using the PC program (manual section 4, pp.23 to 29)

1. Download "VNA View" from the maker's software page (Links tab). It runs on Linux, Windows 7 or newer, and Mac OS 10.11 or newer (p.23). Connect the USB cable.
2. Pick the device in the Device menu; a continuous sweep starts at once (p.25). Windows may need the Cypress USB serial driver from the VNA View downloads (p.25).
3. Sweep settings are under Device → Sweep parameters; the "nValues" field under "Show advanced settings" is the averaging: higher means less noise and a slower sweep (p.26).
4. Calibration on the PC: use Clear and Clear Measurements, choose SOL for one port or SOLT for two, click Open, Short, Load (and Thru for SOLT) in turn as you connect each standard, then Apply (p.27). Changing the sweep range on the PC always clears the active calibration (p.27).
5. Save or load a calibration: Calibration → Save as… / Load… (p.27).

### G. Switch-off checklist

1. Photograph the plot, then write down the calibration slot, start / stop, cable ID and the date.
2. Disconnect the part, then the cable. Put the connector savers back and cap the ports.
3. Charge the battery if the LEDs are low (p.6). Remember the VNA stays off during any real listen with the cage closed.

Not verified from the manual (so we do not give steps):

- How to power the unit on and off (the manual does not describe it in the sections we read).
- The default number of sweep points and how to change it on the device.
- Where the IF bandwidth is set on the device (the data sheet lists the values; the manual's menu list does not say).
- Marker search (find minimum / maximum) and smoothing / averaging menus on the device itself.
- Saving screenshots or traces on the device; exporting from the device.
- Exact mode names in the time-domain menu beyond those listed, and any menu changes in firmware newer than 2022/11.

For these, use the PC program or the maker's current manual page (Links tab). The videos below show other NanoVNA-family models, whose menus are similar but not identical to this one.

## Manuals, videos and the papers

Every link below was fetched on 2026-10-03 and loaded. Video titles and channels were confirmed from YouTube's own embed information. None of the videos is specific to the VNA6000; they are the best-matching NanoVNA-family teaching videos, and the buttons differ somewhat from Dan's model.

### Manuals and maker pages

- VNA6000 User Manual 2022/11 (PDF, 30 pages) (https://nanorfe.com/downloads/vna6000_manual.pdf) — NanoRFE. Sections used: 1 Introduction pp.3 to 6; 2 User interface pp.7 to 10; 3 Performing measurements pp.11 to 22; 4 VNA View PC software pp.23 to 29.
- VNA6000 Specifications (PDF, 5 pages, 2022/08) (https://nanorfe.com/downloads/vna6000_specifications.pdf) — NanoRFE. Frequency range, power, dynamic range, limits.
- VNA6000 product page (https://nanorfe.com/vna6000.html) and product details (https://nanorfe.com/product-vna6000.html) — NanoRFE.
- NanoVNA-QT (VNA View) software (https://nanorfe.com/nanovna-qt.html), NanoRFE software list (https://nanorfe.com/nanovna-software.html), NanoRFE manuals list (https://nanorfe.com/nanovna-manuals.html) and NanoVNA-Saver page (https://nanorfe.com/nanovna-saver.html).
- Local: the hub's own notes on this unit are at kit.html#vna6000, and a shorter engineer-to-engineer draft of bench notes (also from the same manual) is at vna-howto.html.

### Videos (verified title and channel)

Video (click to open) | Channel | What it covers, and how to use it
#312: Back to Basics: What is a VNA / Vector Network Analyzer (https://www.youtube.com/watch?v=Sb3q8f0NBZc) | w2aew | Start here. Plain explanation of what a VNA measures (about 17 min).

#313: Why a VNA needs to be calibrated | how to calibrate a nanoVNA | w2aew (https://www.youtube.com/watch?v=x-tbvAbh9jk) | w2aew | Calibration (open, short, load, thru) on a NanoVNA. Matches Section B.

#314: How to use the NanoVNA to sweep / measure an antenna system's SWR and optimize its tuning (https://www.youtube.com/watch?v=xa6dqx9udcg) | w2aew | S11 and SWR of an antenna. Matches Recipe 1.

#315: How to use the NanoVNA to measure a low-pass filter (https://www.youtube.com/watch?v=F17mN5uuzGY) | w2aew | S21 of a filter. Matches Recipe 4.

#316: Use NanoVNA to measure coax length - BONUS Transmission Lines and Smith Charts, SWR and more (https://www.youtube.com/watch?v=9thbTC8-JtA) | w2aew | Cable length and Smith chart extras. Matches Recipe 3.

#274: Smith Chart Basics: Impedance and Admittance curves and conversion (https://www.youtube.com/watch?v=gw1TYWwfvGk) | w2aew | Optional: reading the Smith chart.

NanoVNA & LiteVNA Calibration & Antenna Tuning (https://www.youtube.com/watch?v=mQLBrq85UXk) | TAKEAPART | Short (about 3 min) calibration and antenna tuning, with a 433 MHz antenna sweeping 420 to 455 MHz. Close to our Experiment B band.
NanoRFE VNA6000 Temperature Drift 1h (https://www.youtube.com/watch?v=GxSWYBd888M) | NanoRFE Ch. | The maker's own video of this model, showing how readings drift while it warms up. IDEA Let the unit warm up before a careful measurement.

### The papers (public-safe links only)

Source | Link | Note
Nikolova & Zimmerman 2007, McMaster report CEM-R-46 | Hub copy (PDF) | University technical report; hosted on the hub library.
Zimmerman 2011, Mod. Phys. Lett. B 25(9) 649 | Publisher DOI page (https://doi.org/10.1142/S0217984911026024) | Publisher page only; read it through the hub library card or the publisher.
Zimmerman 2013, J. Appl. Phys. 114, 044907 | Publisher DOI page (https://doi.org/10.1063/1.4816100) | Publisher page only.
Zimmerman 2011, QEX July/August | ARRL QEX (https://www.arrl.org/qex) | ARRL members can read the issue.
Monstein & Wesley 2002, Europhys. Lett. 59(4) 514 | Publisher DOI page (https://doi.org/10.1209/epl/i2002-00136-9) · author-hosted PDF (https://www.jamespaulwesley.org/Document_Files/Observation_of_scalar_longitudinal_electroydnamic_waves.pdf) | No VNA.
Butterworth et al. 2013, J. Sci. Explor. 27(1) 13 | Journal page (https://journalofscientificexploration.org/index.php/jse/article/view/477) | No VNA.
Hively, US 9,306,527 B1 | Google Patents (https://patents.google.com/patent/US9306527B1/en) | Names a network analyzer (col. 7).
Hively & Loebl 2019, Physics Essays 32(1) 112 | Publisher DOI (https://doi.org/10.4006/0836-1398-32.1.112) · hub library card | Erratum link on the library card is the publisher's DOI only.
Navy / Keyport, US 12,525,711 B1 | Google Patents (https://patents.google.com/patent/US12525711B1/en) | No VNA found.
Chiao et al., arXiv:1301.4270 | arXiv (https://arxiv.org/abs/1301.4270) | Network analyzer at 11.5 GHz, above the VNA6000 range.
All library papers | Hub library | Public library page.

Analysis / guide page, GitHub-only: there is no Wolfram Cloud twin planned. FACT items are what the cited source prints; HYP items are the authors' interpretations or the SLW claims; IDEA items are our suggestions for the bench. No outside services or tracking on this page. Related: loss-mode comparison · equation map · corrections.

Dan Britton · SLW Hub · Simulation Lab catalogue
Educational use only. Scalar-longitudinal-wave claims are not settled physics.

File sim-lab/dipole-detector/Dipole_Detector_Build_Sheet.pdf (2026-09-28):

# DIPOLE DETECTOR — BUILD SHEET

An instrument, 3 variants: DD-433 (Exp. B, 433.59 MHz M&W) · DD-1296 (Exp. A, 1296 MHz) · DD-2450 (2.45 GHz oven test)

THIS IS A RECEIVING ANTENNA,

NOT a Monstein & Wesley passive polarizer rod.

It replaces one rod in the array for detection only.

## 1. CUT LENGTHS (1/8 in = 3.175 mm brass rod, 1.5 mm feed gap)

| DD-433 433.59 MHz | DD-1296 1296 MHz | DD-2450 2450 MHz
Wavelength | 69.1 cm | 23.1 cm | 12.2 cm
CUT at (tip to tip, long) | 345.7 mm (13.61 in) | 115.7 mm (4.55 in) | 61.2 mm (2.41 in)
each half at cut | 172.1 mm (6.78 in) | 57.1 mm (2.25 in) | 29.8 mm (1.17 in)
EXPECTED final (tip to tip) | 332.2 mm (13.08 in) | 109.6 mm (4.32 in) | 57.2 mm (2.25 in)
each half, final | 165.4 mm (6.51 in) | 54.1 mm (2.13 in) | 27.9 mm (1.10 in)
trim per tip (about) | 6.7 mm | 3.0 mm | 2.0 mm
Balun sleeve, start (VF 1.00) | 172.9 mm (6.81 in) | 57.8 mm (2.28 in) | 30.6 mm (1.20 in)
Balun sleeve if taped (VF 0.95) | 164.2 mm (6.47 in) | 54.9 mm (2.16 in) | 29.1 mm (1.14 in)

Half = (tip-to-tip − 1.5 mm gap) ÷ 2, measured from the gap end of the rod to its tip. CUT LONG, then trim both tips equally in

small steps (0.5 mm), checking resonance with a VNA, or TinySA + generator + return-loss bridge. Aim for the lowest SWR at the band. Expected final = free-space half-wave × thickness factor K (DD-433 0.961, DD-1296 0.948, DD-2450 0.935), read from the classical chart

RSGB Handbook 2011 Fig 16.1 (G8EZE). Published charts disagree slightly, so TRIM, don't trust. A computer check (openEMS) agreed the thick rod is ~3–4 % shorter than thin wire at 2450 MHz. Inside the cage the resonance moves: do the final trim IN THE CAGE.

### WHY 1/8 in BRASS IS FINE FOR ALL THREE

- Stiff: holds its shape without a support.
- Solders easily to the SMA jack.
- Thickness only makes the cut length a few % shorter

(already in the table above).
- A thicker rod gives a broader, easier-to-hit tuning

range than thin wire.
- Brass is chosen for its electrical conductivity (about 3× tungsten W1) — nothing else.

## 2. FEED + BALUN (top view, not to scale)

rod half (brass) | rod half (brass)

gap 1–2 mm — NO solder here

SMA edge-mount jack: center
pin → one half, tab → other half

BALUN SLEEVE (copper tube or tape), length from table. Open end toward the dipole: touches nothing.

Far (cold) end soldered all
round to the braid (red line).

### Why: the sleeve stops signal current running back along the outside of the coax, so the cable

doesn't act as part of the antenna.

coax leaves at 90°
(RG-174 assumed —
check Dan's cables)

### 3. HOW TO SOLDER

1. Cut halves LONG (table). File ends square.
2. Tin the gap end of each rod and the SMA pin + tab.
3. Clamp both halves on a straight edge: in line, gap 1–2 mm.
4. Solder one half to the center pin, the other to the ground tab. Small, quick joints. NO solder bridging the gap.
5. Check tab geometry on the Amphenol 132322 datasheet first.
6. Balun: 2 layers tape over jacket → slide sleeve on → open end at the jack → solder FAR end to braid → heat-shrink.

## 4. MOUNTING + CAGE (side view)

sealed Faraday cage
(its own cage: see CAGE_ESTIMATE)

Lazy Susan

HDPE or acrylic plate

nylon clamps or tape
(no metal screws near rod)

TinySA

TinySA Ultra on its OWN
BATTERY, ~30 cm coax.
Record, then open the cage.

coax leaves at 90° to the rod

NO CABLE CROSSES THE CAGE WALL. No feed-through, no bulkhead.

### WHAT THIS MEASURES

HYPOTHESIS (SLW): the dipole couples to the longitudinal field through charge build-up (Hively, J = σE; US 9,306,527), and the TinySA reads

the signal induced at the feed gap.

ORDINARY RADIO (classical fact): any dipole also picks up normal radio waves. The closed cage is there to block those. Whether the SLW gets through the cage wall is a HYPOTHESIS being tested.

Brass is specified for its conductivity (σ) only.

SAFETY: detectors, rods and TinySA stay OUTSIDE the oven cavity.

Never put anything inside a running microwave oven.

### PARTS (all 3 variants; see PARTS_LIST.md)

- Brass rod 1/8 in: 523 mm total cut → buy 2 × 36 in

or 5 × 12 in (generic)
- SMA edge-mount jack Amphenol 132322 (Digi-Key

ACX1652-ND): 3 + 2 spares
- 3 SMA coax pigtails ~30 cm (RG-174 assumed, or

Dan's existing assemblies)
- Thin-wall copper/brass tube or copper tape, heat

shrink, nylon clamps, HDPE plate

## Dipole Detector DD-433 / DD-1296 / DD-2450

Grok Bot initial design — VERIFY BEFORE CUTTING

Rev A 2026-09-27 Prepared for Dan Britton (builder: Steve Morris)

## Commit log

2026-08-31 Add bench setup page: Cricut sticky-mat bifilar winding at 1.3 GHz.
    Walks through the gummy-board pancake (22/24 AWG), series-opposing connection, and cage/stub first measurements for the Hively replication.
2026-08-31 Setup page: fold-in-half bifilar, TinySA Ultra 406, RadioScreen mesh cages.
    Drop the 1.3 Hz aside. One 2.2 m strand folded at the hub (no center solder) with DMM open-circuit check. No 51 ohm pad on the detector. Two Less EMF RadioScreen tents with instruments inside.
2026-09-01 Setup: pancake lift-off, RX/TX fixtures, Lady Lake–Middletown packing
    Document Cricut StandardGrip lift-off, planar nylon-fastened RX/TX sleds, removable mesh flap seals, and a travel packing checklist. Lab protocol cross-links those steps. Licensed 23 cm / 1296 MHz only.
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2026-09-01 Switch fields page from Three.js to a 2-D canvas cartoon. (#4)
    Keep TinySA dBm, r, two-tent RadioScreen, TEM vs SLW, Zimmerman A(r), listed equations, SNR. No WebGL dependency.
2026-09-01 Add downloadable Wolfram Manipulate source next to fields.html. (#5)
    So the .wl can be opened from the hub without a chat attachment.
2026-09-01 Add Monstein–Wesley 2002 educational page. (#7)
    Brass-rod polarizer formulas from EPL 59, 514; Hively 2026 distinction paraphrased (no private email). DOI only, no IOP PDF. Links from hub nav.
2026-09-01 Monstein page: Meyl ball kit is HF pancake, not Hively rod protocol. (#9)
    Honest mismatch note; no potential-vortex overclaim.
2026-09-02 Separate pancake-cage (A) from Monstein polarizer (B) shopping lists
    Keep 1296 MHz RadioScreen/pancake protocol on setup/lab/fields with a one-line different-experiment link. Put verified 433.59 MHz ball+rod parts only on monstein.html#parts.
2026-09-02 Add 23 cm TX bandpass buy links to setup.html shopping list.
    Drop-in Mini-Circuits ZX75BP-1307-S+ (and DEM-BPF ham option) between TinySA Ultra generator and SMA stub, with stable #bpf anchor.
2026-09-02 Clarify TinySA Ultra RF jack is SMA-F despite external brass threads.
    Add the same sentence at #bpf and the generator caveat so the Ultra is not treated as SMA-M. Chain stays Ultra SMA-F to filter SMA-M to filter SMA-F to SMA-M stub.
2026-09-02 Remove Wolfram Cloud cartoons from live hub pages.
    Keep the 2D JS TEM/SLW canvas as the 1296 MHz viz and add an interactive Monstein T(φ) slider. Leave SLW-TEM-fields-1296MHz.wl in the repo as a source drop only.
2026-09-02 Add Experiment B sphere substitute page for Hively correspondence
    Educational comparison of a procurable 2.50 in 3003 hollow Al sphere plus SMA 901-9875 against Monstein & Wesley 2002 Fig. 1 machined 60 mm ball antennas. Images via Git blobs. Link from monstein.htm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
2026-09-03 Nine 34.6 cm rods need five 36-inch sticks, not four (brass and W1)
2026-09-03 Two-experiment nav, sleeve-not-skirt build, shared field kit
    Rewrite index.html as hash-deep-linkable tabs (A 1296 cage, B 433 balls, shared kit). Add kit.html. Experiment A build is a close-fitting sleeve balun, not the patent skirt. Experiment B has no balun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
2026-09-03 Index kit tab: not-first-buy one-liners (Nanuk, SKB, B&W, Zarges, WTE)
    Keep the master #kit tab aligned with kit.html#cases: first buy remains Pelican 0340;
    alternatives stay one-liners, not hull SKUs.
2026-09-05 Add Monstein & Wesley 2002 Fig.5 power vs distance for SW/SLW Joule-loss note
2026-09-05 Revise c-nuclei.html: 2026-09-05 wider-net revision
    Library-first channels A–D refined; add E–I (7Be EC, 14N NQR, scalar AB, Mössbauer, HCI scalar template), Rentzber 2608.19405 detector constraint, yesterday-vs-today section.
2026-09-05 Fix Nature 2021 cite (Heeg et al. Nature 590, 401–404) on c-nuclei.html
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2026-09-06 Add Tomilin–Lukin–Gulkov 2021 Tech. Phys. Lett. marine radio channel PDF (Hively email set)
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2026-09-06 Wire Tomilin 2021 + Avsharov EN downloads for Hively p.36 library cluster
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2026-09-09 Experiment C cart shortlist: optical + TinySA chain rough USD
2026-09-09 Experiment C SNR v1: four plots + PMT cathode/anode current + TinySA tone
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2026-09-13 Fix Experiment D–F buttons: live URLs + tab hash map (index.html)
2026-09-13 Fix Experiment D–F buttons: live URLs + tab hash map (js/app.js)
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2026-09-16 Clarify KB-1820 ships with no hole; only KB-2016 has stock ¼″ (index.html)
2026-09-16 Clarify KB-1820 ships with no hole; only KB-2016 has stock ¼″ (setup.html)
2026-09-16 Archive Cricket/Cricut sticky-mat + bifilar + sleeve under #archive-bifilar; ¾″ KB-1820 sphere is Experiment A first article
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2026-09-19 Add Tekbox TBPS01 H/E probes + Hively B-null protocol for SLW/SW vs TEM
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2026-09-20 library: add Hively & Loebl 2019 Physics Essays citation card (no PDF)
    Closed-access; DOI / publisher / ResearchGate / erratum links. Wire learn.html cite to #hively-loebl-2019.
2026-09-20 library: add Navy US 12,562,930 B2 sensor-system patent (cited by SLW 12,525,711)
    USPTO PDF + card; cross-link with navy-us12525711.
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2026-09-24 sleeve-balun-snr v0: CoS RESEARCH fold-in (#39)
    - TinySA Ultra gen max −19 dBm (tinysa.org TinySA4); I@−19 ≈ 0.50 mA rms / 0.71 mA pk
    - No RG-450/U; sleeve host RG-405/U; jumpers RG-316-class; Ultra alone never thermally limits coax
    - PATENT US 12,525,711 λ/4 sphere ≠ LAB KB-1820 / KB-2016 (explicit UI + JSON)
    - US 12,562,930 flagged sensor/DAQ only — not balun dims
    - Dual Ohmic: Errata α=0 (EED) vs Exp-C Ohmic HYP; SW α=0
    - Sub stack lengths from Linearly Resistive LEN (no attenFactor 0.95)
    - physics-constants.json snr-dual-sim-params-v0 for Mathematica parity
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2026-09-24 fix(sleeve-snr): keep Ohmic media stack checkboxes clickable (#43)
    Errata α=0 / SW still force α=0 in compute, but media segment boxes
    and cageOhm stay enabled so clicks register. Only α magnitude sliders
    disable while locked; note + dashed outline explain the state.
2026-09-25 Future experiments: home bench Experiment D (driven Faraday sphere, E5/stub/H20 interior probes, EED vs leakage predictions) (#45)
2026-09-25 FX-1 SNR simulator fx1-snr-v0.1: Pages page + JS engine, shared constants, Wolfram twin (Cloud pending sync) (#49)
    - fx1-snr.html + js/fx1-snr.js: interior standard (Schelkunoff wall + Ott seam leakage) vs EED HYP E_r,
    exterior near/far (quasi-static sphere, line-current and point-dipole Hertzian models, power-limited),
    SleeveBalunSNR media stack + HDPE, Tekbox TBPS01 E5/H10/H20/H5 factors (manual V2.2 / FAQ V1.1),
    TinySA Ultra floor vs RBW, SNR; openEMS FDTD reference block
    - physics-constants-fx1.json: single source (version fx1-snr-v0.1); injected into JS and WL
    - wolfram/FX1SNR.wl (+ _Publish, _RunGrid, PHYSICS_LOCK.md, check/dump/compare scripts)
    - future-scalar-ab.html: link from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
2026-09-25 physics-constants: fix -19 dBm I_rms/I_peak transcription error (+ derived efield P_rad) (#50)
    at_Pmax_m19_dBm listed I_rms 5.018722e-4 / I_peak 7.097546e-4 A, off by 1.8e-4 rel from
    sqrt(P_W/50) with the file's own P_W (implied R 49.982 ohm; I_pk/I_rms != sqrt 2).
    First seen hand-authored in e55b8bf (with js TINYSA.IrmsAtM19/IpkAtM19), copied into
    efield_maps.I_peak_A_at_drive + P_rad_Eq15_W_at_drive in 0678ae9. The Mathematica output
    (IFromPtx[-19.], efield_summary.json, I_pk_A_lock) is 7.096267784671506e-4 A, which matches
    the recomputation. Now I_rms = 5.017819071656863e-4, I_peak = I_pk_A_lock, P_rad = Prad_W_lock.
    Same fix applied to the unused js constants. Simulators compute I from d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
2026-09-26 experiment-c: fix inverted charge-relaxation exponent to E = E0 exp(-sigma t/eps), tau = eps/sigma; add FACT note (#58)
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2026-09-28 Add /sim-lab/ catalogue + Pages twins for 9 finished sim-lab reports; hub index card (#61)
    * WIP: /sim-lab/ report pages (faithful conversions of finished sim-lab reports)
    * WIP: /sim-lab/ catalogue + hub index card
    * sim-lab: catalogue anchors scroll margin, linkify URLs in reports
    * sim-lab reports: fix pipe/asterisk Markdown rendering (no value changes)
    ---------
    [home_motor_numbers.json]
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2026-09-30 Author-confirmed charge-relaxation exponent E=E0 exp(-sigma t/epsilon), tau=epsilon/sigma (Hively, private email 2026-09-30): notes on experiment-c, experiment-c-snr, sleeve-balun-snr, joule-loss-pos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
2026-09-30 New /sim-lab/loss-modes/ (three readings of SLW loss: Joule-literal, Erratum alpha=0, charge relaxation HYP; M&W Rhine geometry) and /sim-lab/equation-map/ (equation source and meaning map); catalogu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
2026-10-04 Add three-position rod fixture scan (proposal): exp-433/1296/2450, oven, joule-loss analysis + calculators F/G, to-do group, CSV template
    [three-station-template.csv]
2026-10-05 Exp B: full 0-360 rotation scan for brass and W1 (annealed), open run then planned caged run, per Dan's Oct 5 email; to-dos, CSV template, calculators accept 0-360
    [three-station-template.csv]
2026-10-05 Exp A feed corrected: RG-405U centre conductor soldered into #76 pin hole, shield kept off the 3/4 in sphere; feed table on exp-1296, superseded bulkhead/centre-tip text, to-dos
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2026-10-08 Experiment H: correct Standing Wave Project hollow-sphere claim (it imports STL/OBJ/GLTF meshes, no login, FEM eigenmodes); add hollow sphere modes for K-Mac KB-1820 and KB-2016 with scaling, cross-c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
    [kb1820-0.75in-closed-shell-1mm.stl, kb2016-2.5in-shell-3.35mm-quarter-inch-hole.stl]
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2026-10-08 Round 1 rods: add rod ringing and settle time note (rod-jig #ringing, exp-433/1296/2450, oven, todo, CSV settle_s); library: O-Animator toroid A vs B figure for toroid cards, credit Bob Greenyer
    [three-station-template.csv]
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2026-10-08 Exp B (exp-433): add caged rod fixture configuration (run table, build notes, waveguide-below-cutoff shaft, wall clearance, shielding check); fixture_cage log column in pages and CSV template
    [three-station-template.csv]
2026-10-08 Exp B (exp-433): add Dan's string and drill turning method (#drill-turn), Better ideas welcome note, turn_method log column
    [three-station-template.csv]
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2026-10-08 Oven page: rod fixture wording
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2026-10-15 sleeve-balun: as-built K&S tube, taped stub correction (#taped-stub)
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2026-10-16 NANUK packing: TinySA RF port photo, swap point manifolds, H10 or E5 probe TinySA, excess metal note
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2026-10-16 NANUK packing: direct vs cabled cartoon, direct default for sphere assemblies, noise coupling decision
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
